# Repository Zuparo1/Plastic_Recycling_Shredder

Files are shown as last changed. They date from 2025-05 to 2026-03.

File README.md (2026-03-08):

# 🌍 Open-Source Plastic Shredder for 3D Printing Waste

**A modular, self-fabricated shredder designed for labs, makerspaces, and classrooms around the world. Built with affordable materials and hobby-grade tools, this project supports circularity, sustainability, and accessible engineering.**

Animations: 
https://drive.google.com/drive/folders/1GTDH_LksxOAHPd8L4uIryJ2b2BNffAHZ?usp=sharing
---

##  About the Project

As 3D printing becomes more widespread, so does its waste—failed prints, supports, and excess prototypes. This open-source shredder enables small-scale recycling of that plastic into material suitable for extrusion into new filament.

Our design prioritizes:
-  **Making** – We emphasize fabrication, not just CAD.
-  **Accessibility** – Built from globally available tools and materials.
-  **Sustainability** – Aligned with UN SDG 12 for circular production.

All files, documentation, and build guides are included to help you fabricate and adapt the shredder in your own lab or makerspace.

---

##  What's Included

-  [Build Manual](Manual.pdf): Step-by-step instructions with safety tips and fabrication guidelines
-  [STEP](/STEP) files for the Shredder, gearbox, and housing
-  [Fusion 360](Fusion%20Models) files
-  [Arduino code](ArduinoCode/ArduinoDigiFabFinal/ArduinoDigiFabFinal.ino)
-  [Bill of materials](/Bill%20of%20Materials) with sourcing notes

---

##  What You'll Need

**Tools:**
- Laser cutter
- FDM 3D printer (e.g., Prusa, Creality)
- CNC router (optional for motor mount)
- Basic hand tools and soldering equipment

**Materials:**
- MDF wood (6mm / 16mm)
- PLA, ABS, or PC+ filament
- Bearings (608ZZ, 6002 2RS, etc.)
- Bolts and nuts (M3–M6)
- Gear motor (~\$40, or cheaper alternatives)

Full details in the [manual](Manual.pdf).

---

##  How It Works

1. Print your model
2. Shred failed or excess prints into pellets
3. Extrude into new filament
4. Repeat 

---

##  License

This project is released under the **CERN-OHL-W v2** license, allowing you to use, modify, and distribute it freely, with the condition that improvements are shared under the same license.

---

##  Contributions Welcome

Feel free to fork, remix, or submit pull requests for improvements! We welcome:
- Translations
- Alternative gear/motor configurations
- Safety features or electronics add-ons
- Field testing results

---

## 📫 Contact

Made by  
- Torstein Mo Kirkeluten – `torstemk@hiof.no`  
- Jacob Holth – `jacobh@hiof.no` /  `Zuparo1@hotmail.com`
- Moritz P. Nedland Halkjelsvik – `mphalkje@hiof.no`

Faculty of Computer Science, Engineering and Economics  
Østfold University College, Norway

---

*Help us make sustainable 3D printing a global reality.*

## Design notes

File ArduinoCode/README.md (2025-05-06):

This fodler contains the code for the Arduino Control Box

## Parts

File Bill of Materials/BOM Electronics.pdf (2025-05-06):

# BOM Electronics

This document outlines essential components required for building the shredder.

## Components

The following table lists the components necessary for assembling the electronics. Optional components are marked with *

ID | Item | Material | Quantity | Link
1 | Arduino Uno | | 1 | https://store.arduino.cc/products/ard uino-uno-rev3?srsltid=AfmBOoryz0 R57xpHzzZM81fNsVgdM2d6e5Gq1 D9oCW6n_iAZb1saQQDX (https://store.arduino.cc/products/arduino-uno-rev3)
2 | 16x2 I2C LCD Display Address: 0x27 | | 1 | https://www.aliexpress.us/item/1005 006085343415.html?src=google&pd p_npi=4%40dis%21EUR%211.21% 211.21%21%21%21%21%21%40% 2112000035661666782%21ppc%2 1%21%21&src=google&albch=shop ping&acnt=298-731-3000&isdl=y&sl nk=&plac=&mtctp=&albbt=Google_ 7_shopping&aff_platform=google&a ff_short_key=UneMJZVf&gclsrc=aw. ds&albagn=888888&ds_e_adid=&d s_e_matchtype=&ds_e_device=c&d s_e_network=x&ds_e_product_grou p_id=&ds_e_product_id=en100500 6085343415&ds_e_product_merch ant_id=5089408953&ds_e_product _country=NO&ds_e_product_langu age=en&ds_e_product_channel=onl ine&ds_e_product_store_id=&ds_ur l_v=2&albcp=21627925185&albag= &isSmbAutoCall=false&needSmbH ouyi=false&gad_source=1&gad_ca mpaignid=21634522559&gbraid=0A AAAAqc5ie1OKkm5g4Uzg7gkq1CR bybP_&gclid=Cj0KCQjw5ubABhDIA RIsAHMighZQxXRg8FOkbWryVEXl rHnaxIR6BKWgDFGf5LjG0Isgq0eE oFPellsaAloSEALw_wcB&gateway Adapt=glo2usa (https://www.aliexpress.us/item/1005006085343415.html?src=google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)
3 | Momentary Push Button | | 1 | https://www.aliexpress.us/item/3256 (https://www.aliexpress.us/item/3256805662396061.html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)

## Components

The following table lists the components necessary for assembling the electronics. Optional components are marked with *

ID | Item | Material | Quantity | Link
| | | | 805662396061.html?spm=a2g0o.pr oductlist.main.21.6cbf1f18OKJsNd& algo_pvid=3d2ef3f2-b68c-44ce-b9fd -54fd0e0a57cc&algo_exp_id=3d2ef 3f2-b68c-44ce-b9fd-54fd0e0a57cc- 10&pdp_ext_f=%7B%22order%22% 3A%2275%22%2C%22eval%22%3 A%221%22%7D&pdp_npi=4%40dis %21USD%211.76%211.56%21%21 %211.76%211.56%21%402103956 a17465421417618754e26d2%2112 000034565686333%21sea%21US %210%21ABX&curPageLogUid=7P etJtaaquGC&utparam-url=scene%3 Asearch%7Cquery_from%3A (https://www.aliexpress.us/item/3256805662396061.html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)
4 | WS2812B LED Strip 4 LEDs | | 1 | https://www.fibel.no/product/ws2812 b-neopixel-pixel-led-strip/?srsltid=Af mBOopAH0Vv36monS-HPZx3gQyJ 3OkJDmQXrJ0zuG5A_po6k7F0Jrh T (https://www.fibel.no/product/ws2812b-neopixel-pixel-led-strip/)
5 | Piezo Buzzer - PKM22EPPH4002-B0 | | 1 | https://www.digikey.no/no/products/ detail/murata-electronics/PKM22EP PH4002-B0/2595277?gad_source= 1&gad_campaignid=20277145871& gbraid=0AAAAADrbLlj-o2vP-Egd_Zi Wn0xH5Ob-G&gclid=Cj0KCQjw5ub ABhDIARIsAHMighaVh73Tvg7JnuA 5kcsUhn0y8bUVbFrtSQIoYFb33IgO N_E96ZZn-_UaAvWFEALw_wcB&g clsrc=aw.ds (https://www.digikey.no/no/products/detail/murata-electronics/PKM22EPPH4002-B0/2595277?gad_source=1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)
6 | 220Ω resistor | | 1
7 | Breadboard | | 1
8 | Jumper wires | | 17
9 | Housing | PLA | 1
10 | Housing Lid | PLA | 1

## Components

The following table lists the components necessary for assembling the electronics. Optional components are marked with *

ID | Item | Material | Quantity | Link
11 | Mounting Plate | PLA | 1
12 | M3 Screw 16 | Steel | 11
13 | M3 Bolt | Steel | 22
14 | USB A to USB B cable 1.5m | | 1
15 | 5V USB A Power adapter | | 1

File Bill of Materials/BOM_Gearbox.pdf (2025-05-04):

# BOM Gearbox

The gearbox features a modular design composed of various interchangeable parts. This document outlines essential components required for building a single gearbox module, as well as additional components for constructing expansion modules.

## Essential internal components

The following table lists the critical internal components necessary for assembling a single gearbox module.

ID | Item | Material | Quantity | Link
1 | Input Gear | PC+ | 1
2 | Planet Gear | PLA | 4
3 | 608 - ZZ Ball Bearing | Steel | 4 | 608 - ZZ Deep Groove Ball Bearing (https://www.amazon.com/SACKORANGE-100-608-ZZ-Ball-Bearing/dp/B07JB2Y4H3?cv_ct_cx=8mm+id+bearing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)
4 | OutputHub | PLA | 1
5 | 6002-2RS Ball Bearing | Steel | 1 | 6002-2RS Deep Groove Ball Bearing (https://www.amazon.com/dp/B0D8GQGH4Y?s=industrial&sp_csd=d2lkZ2V0TmFtZT1zcF9kZXRhaWwy)
6 | 685-2RS Ball Bearing | Steel | 1 | 685-2RS Deep Groove Ball Bearing (https://www.amazon.com/HARFINGTON-6810-2RS-Bearings-Bearing-Conveyors/dp/B0CGXDDZ8F)
7 | Ring Gear | PLA | 1
8 | Housing (See options) | PLA | 1
9 | Faceplate | PLA | 1
10 | M3 Screw (20-30mm) | Steel | 5
11 | M3 HexNut | Steel | 5
12 | M8 Screw (20-25mm) | Steel | 4
13 | M8 HexNut | Steel | 4

## Expansion components

The components listed below are necessary for building additional modules to expand the gearbox, allowing for greater gear ratios and torque based on specific project requirements.

ID | Item | Material | Quantity | Link
14 | Sun Gear Carrier | PLA | 1
5 | 6002-2RS Ball Bearing | Steel | 1 | 6002-2RS Deep Groove Ball Bearing (https://www.amazon.com/dp/B0D8GQGH4Y?s=industrial&sp_csd=d2lkZ2V0TmFtZT1zcF9kZXRhaWwy)
2 | Planet Gear | PLA | 4
3 | 608 - ZZ Ball Bearing | Steel | 4 | 608 - ZZ Deep Groove Ball Bearing (https://www.amazon.com/SACKORANGE-100-608-ZZ-Ball-Bearing/dp/B07JB2Y4H3?cv_ct_cx=8mm+id+bearing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)
7 | Ring Gear | PLA | 1
8 | Housing (See options) | PLA | 1
10 | M3 Screw (20-30mm) | Steel | 5
11 | M3 HexNut | Steel | 5
12 | M8 Screw (20-25mm) | Steel | 4
13 | M8 HexNut | Steel | 4

## Housing Options

Below are listed various housing designs available for the gearbox. All housings are 3D printed in PLA but feature different configurations based on mounting preferences, intended use (single or double gearbox configurations), and specific project needs.

Item

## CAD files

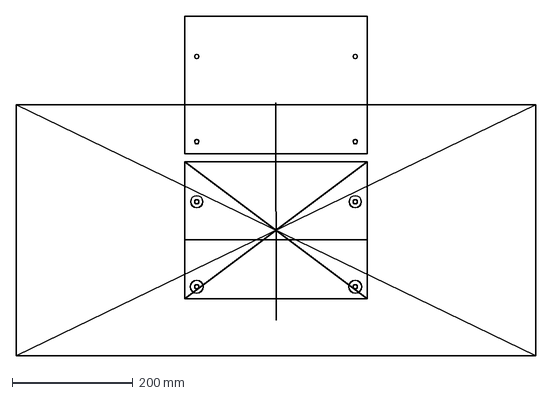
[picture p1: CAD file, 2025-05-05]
Fusion Models/Mountingplate_Cnc.dxf
859.0 x 561.0 mm

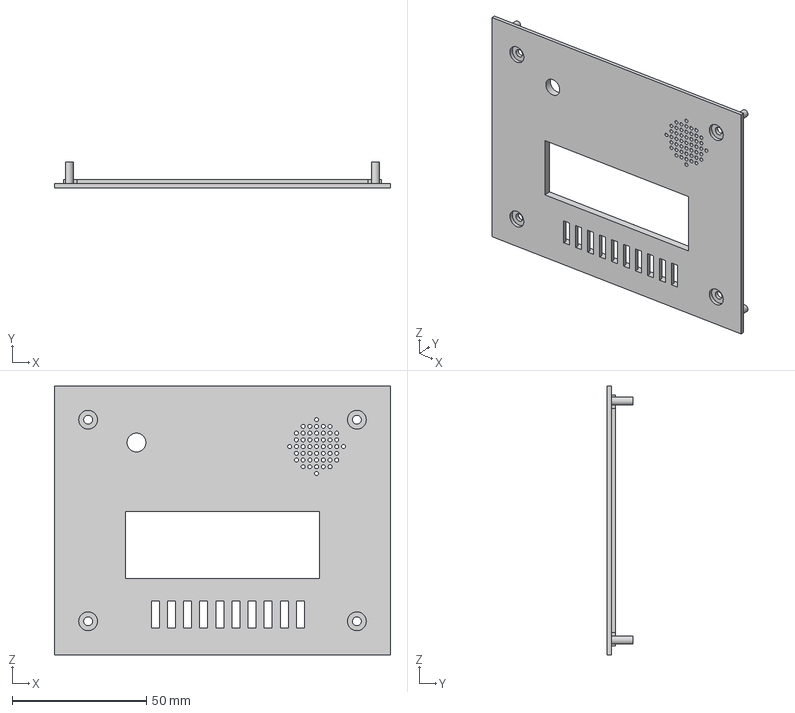
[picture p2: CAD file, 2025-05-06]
STEP/ArduinoControlBox/Arduino_HousingLid _v3.step
125.0 x 9.50 x 100.0 mm

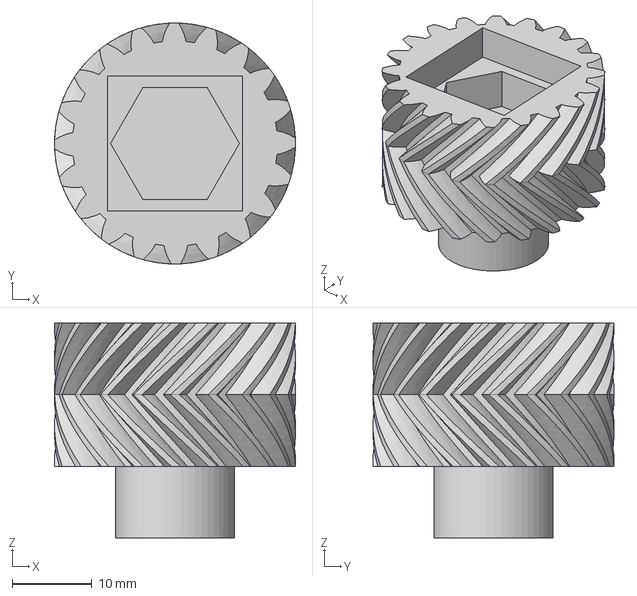
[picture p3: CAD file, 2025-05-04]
STEP/Gearbox/SunGear.step
30.3 x 30.3 x 27.0 mm

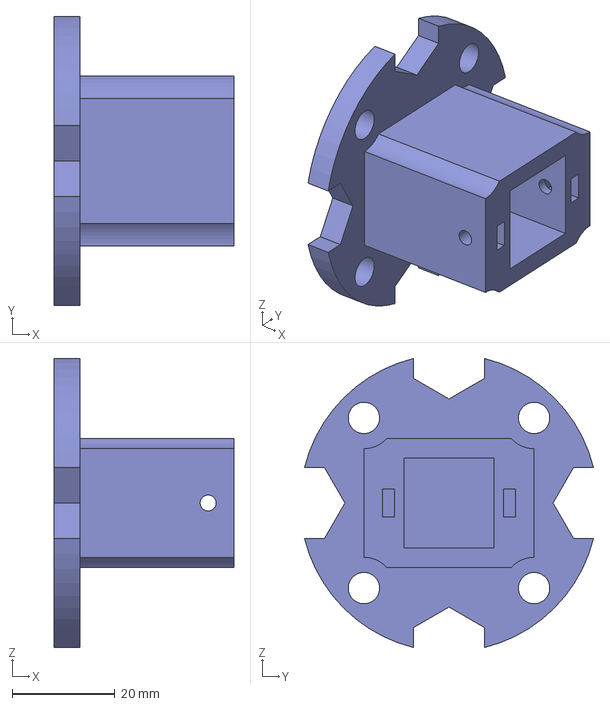
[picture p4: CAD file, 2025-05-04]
STEP/Shredder/GearBox_Axle_Conector.step
35.0 x 56.3 x 56.3 mm

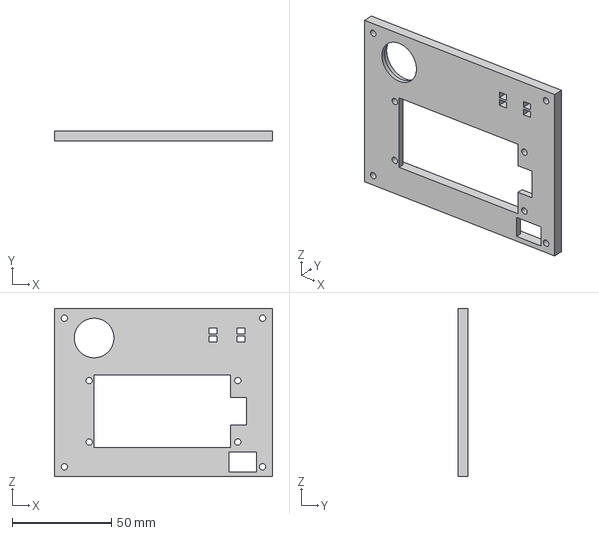
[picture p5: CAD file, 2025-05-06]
STEP/ArduinoControlBox/Arduino_MountingPlate_v4.step
110.0 x 5.00 x 85.0 mm

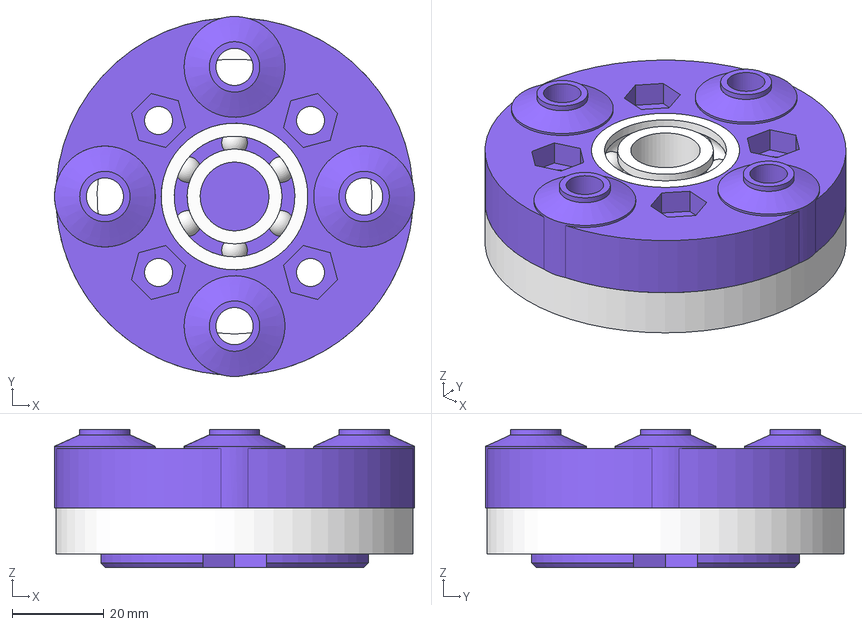
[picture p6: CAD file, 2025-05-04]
STEP/Gearbox/OutputHub.step
78.6 x 78.6 x 30.2 mm
OuterRing
InnerRing
Ball x 6
OuterRing_1
InnerRing_1
Ball_1 x 19

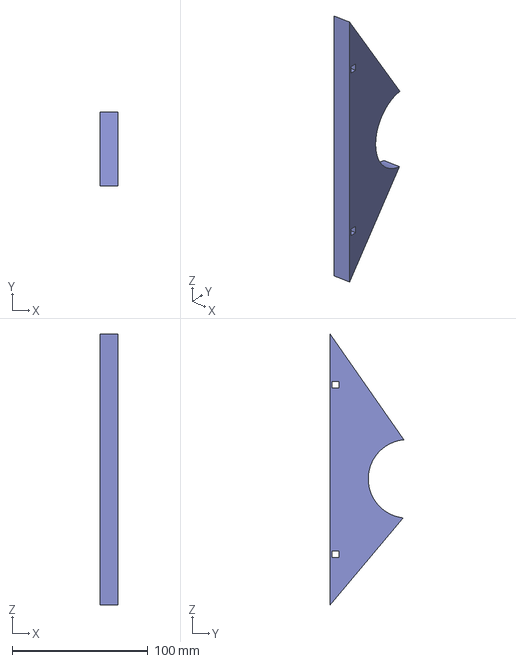
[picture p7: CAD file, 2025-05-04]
STEP/Shredder/wall_spacer.step
13.2 x 54.4 x 200.0 mm

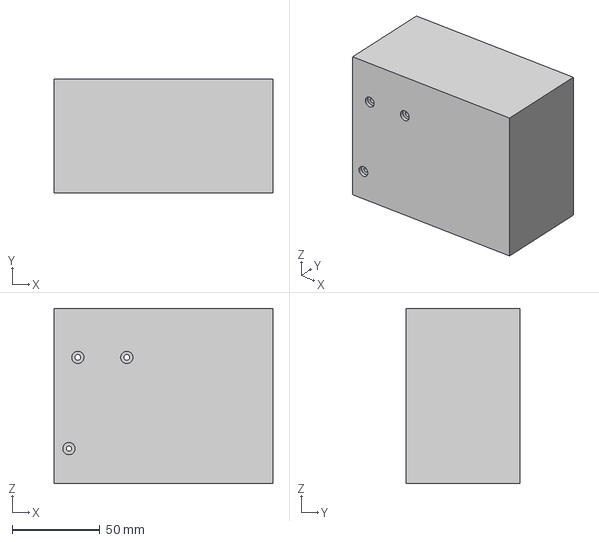
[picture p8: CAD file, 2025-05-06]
STEP/ArduinoControlBox/Arduino_Housing_v7.step
125.0 x 65.0 x 100.0 mm

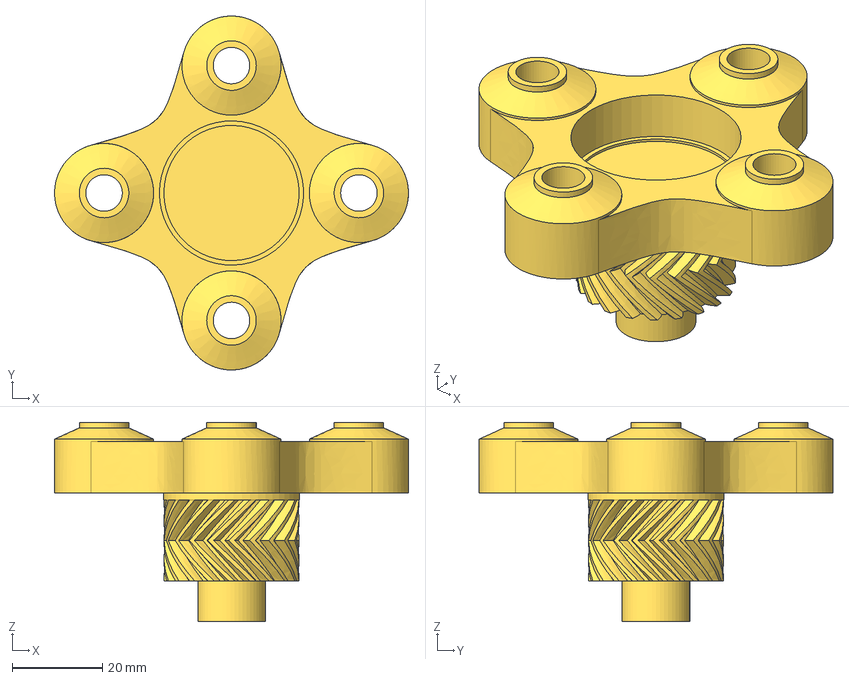
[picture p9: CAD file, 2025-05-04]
STEP/Gearbox/SunGearCarrier.step
78.6 x 78.6 x 44.2 mm

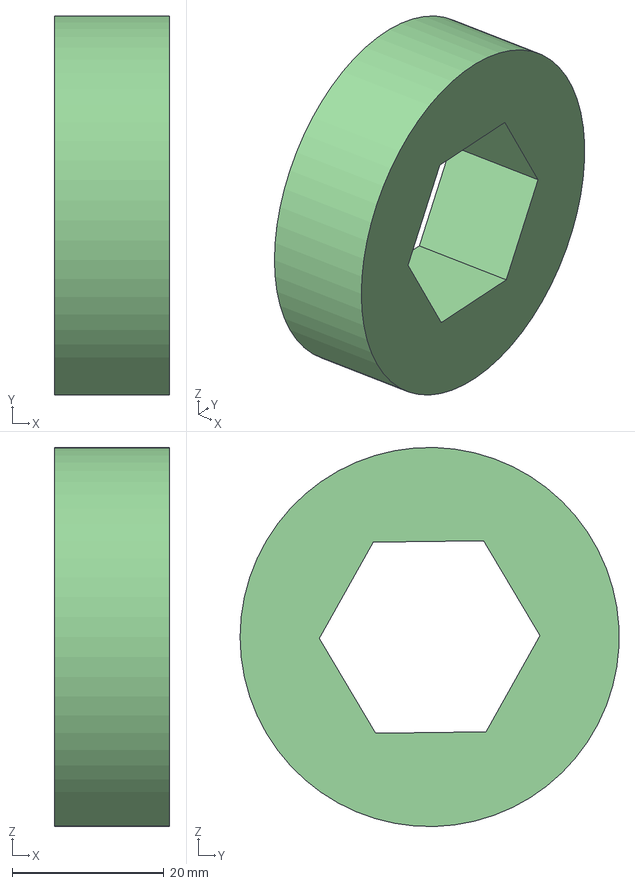
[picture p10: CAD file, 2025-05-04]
STEP/Shredder/Axle_spacer.step
15.2 x 50.0 x 50.0 mm

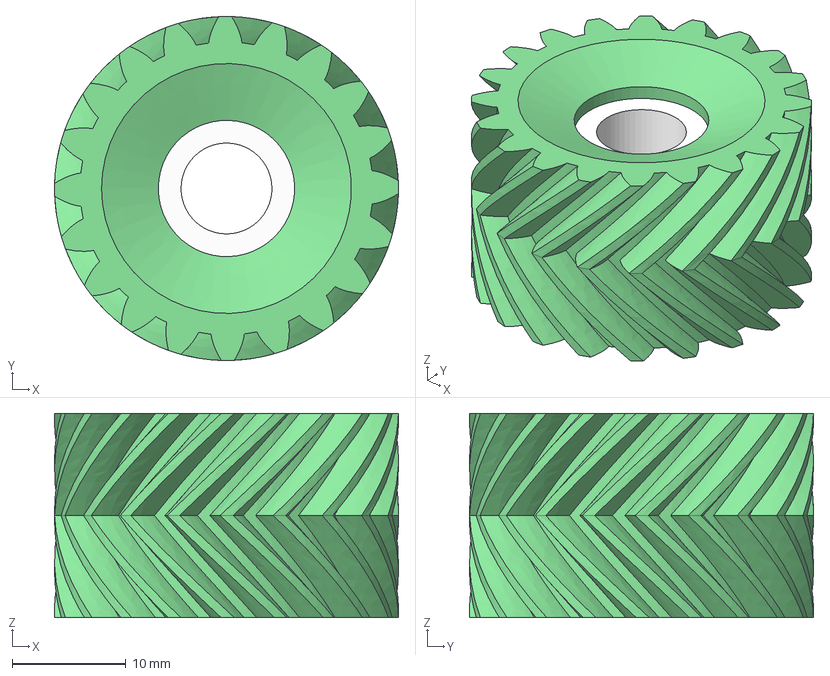
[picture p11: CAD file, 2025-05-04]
STEP/Gearbox/PlanetGear v5.step
30.3 x 30.3 x 18.0 mm
PlanetGear_1
OuterRing
InnerRing
Ball x 4

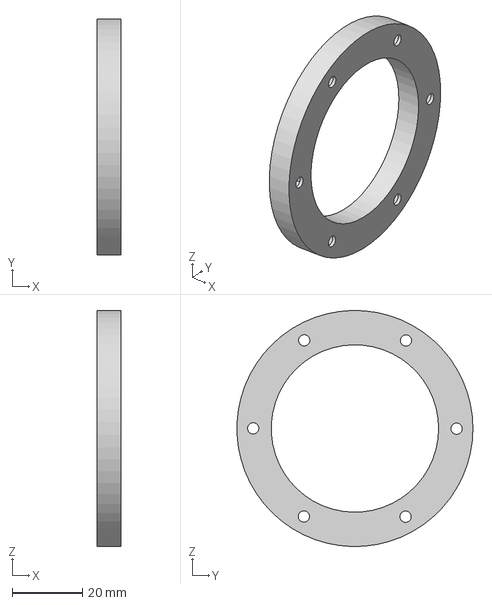
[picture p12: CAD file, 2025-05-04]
STEP/Shredder/Bearing_connector_back.step
6.80 x 67.0 x 67.0 mm

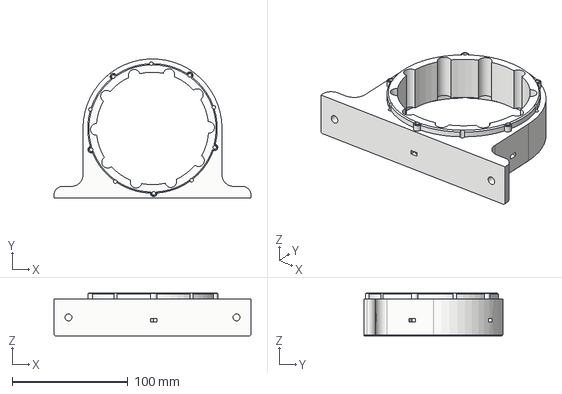
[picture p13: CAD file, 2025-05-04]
STEP/Gearbox/RingGearHolderMount.step
170.0 x 119.9 x 37.0 mm

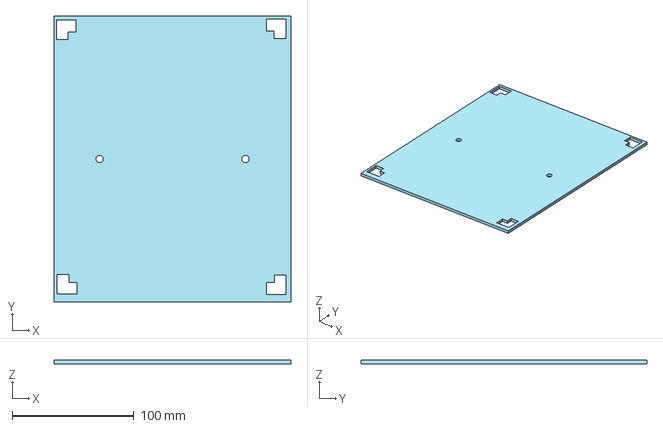
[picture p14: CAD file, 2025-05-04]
STEP/Shredder/roof.step
195.0 x 235.0 x 3.00 mm

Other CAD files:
STEP/Gearbox/RingGearHolderMountDouble v3.step
STEP/Shredder/Wall_spacer_mount.step
STEP/Gearbox/RingGearHolder.step
STEP/Shredder/wall_conectors.step
Fusion Models/Arduino_Housing_v7.f3d
Fusion Models/Arduino_MountingPlate_v4.f3d
Fusion Models/HousingLid v3.f3d
Fusion Models/Main_Shredder.f3z
STEP/Gearbox/FacePlate v2.step
STEP/Gearbox/MotorMount v2.step
STEP/Gearbox/RingGear.step
STEP/Shredder/Axle.step
STEP/Shredder/Bearing_connector_front.step
STEP/Shredder/FrontBack_wall.step
STEP/Shredder/Shredder_Blade.step
STEP/Shredder/roof_handle.step
STEP/Shredder/side_wall.step

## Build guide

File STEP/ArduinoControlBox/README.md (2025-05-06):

STEP Files for the housing unit, used for the Arduino Control Box.

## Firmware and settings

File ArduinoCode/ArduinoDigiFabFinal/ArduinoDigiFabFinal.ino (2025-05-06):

#include <Wire.h>
#include <LiquidCrystal_I2C.h>
#include <Adafruit_NeoPixel.h>

const int buttonPin = 2;
const int buzzerPin = 4;
const int ledPin = 6;

const int numLEDs = 4;
Adafruit_NeoPixel strip(numLEDs, ledPin, NEO_GRB + NEO_KHZ800);
LiquidCrystal_I2C lcd(0x27, 16, 2);


enum ScreenState { STARTUP, IDLE, START_RUNTIME, SHREDDING, DONE };
ScreenState currentScreen = STARTUP;


unsigned long shredStartTime = 0;
unsigned long lastTimerUpdate = 0;
float finalShredTime = 0.0;


bool buttonLock = false;
unsigned long lastButtonTime = 0;
const unsigned long debounceDelay = 300;

void setup() {
  pinMode(buttonPin, INPUT_PULLUP);  
  pinMode(buzzerPin, OUTPUT);

  lcd.init();
  lcd.backlight();
  strip.begin();
  strip.show();

  showStartup(); 
  setLEDColor(0, 255, 0);
}

void loop() {
  unsigned long now = millis();
  int buttonState = digitalRead(buttonPin);

  
  if (buttonState == HIGH && !buttonLock && now - lastButtonTime > debounceDelay) {
    lastButtonTime = now;
    buttonLock = true;
    nextScreen(); 
  }

  if (buttonState == HIGH) {
    buttonLock = false;
  }


  if (currentScreen == SHREDDING) {
  unsigned long now = millis();

  if (now - lastTimerUpdate >= 500) {
    lastTimerUpdate = now;
    float elapsed = (now - shredStartTime) / 1000.0;
    lcd.setCursor(6, 1);
    lcd.print("          ");
    lcd.setCursor(6, 1);
    lcd.print(elapsed, 1);
    lcd.print("s");
  }


  static unsigned long lastFlashTime = 0;
  static bool isYellowOn = false;

  if (now - lastFlashTime >= 500) {
    lastFlashTime = now;
    isYellowOn = !isYellowOn;

    if (isYellowOn) {
      setLEDColor(255, 255, 0);  
    } else {
      setLEDColor(0, 0, 0);      
    }
  }
}
}


void nextScreen() {
  currentScreen = static_cast<ScreenState>((currentScreen + 1) % 5);

  switch (currentScreen) {
    case STARTUP:
      showStartup();
      setLEDColor(0, 255, 0); 
      break;
    case IDLE:
      showIdle();
      setLEDColor(0, 255, 0); 
      break;
    case START_RUNTIME:
      showStartRuntime();
      setLEDColor(0, 255, 0); 
     break;
    case SHREDDING:
      showShredding();
      tone(buzzerPin, 500, 300); 
      setLEDColor(255, 255, 0); 
      break;
    case DONE:
      finalShredTime = (millis() - shredStartTime) / 1000.0;
      showDone();
      tone(buzzerPin, 700, 300);
      delay(500);
      tone(buzzerPin, 700, 300);
      setLEDColor(0, 0, 255);
      break;
  }
}

void showStartup() {
  lcd.clear();
  lcd.setCursor(0, 0);
  lcd.print("Shredder ready");
  lcd.setCursor(0, 1);
  lcd.print("Insert material");
}

void showIdle() {
  lcd.clear();
  lcd.setCursor(0, 0);
  lcd.print("Secure lid");
  lcd.setCursor(0, 1);
  lcd.print("Next page...");
}

void showStartRuntime() {
  lcd.clear();
  lcd.setCursor(0, 0);
  lcd.print("For runtime:");
  lcd.setCursor(0, 1);
  lcd.print("Press when start");
}

void showShredding() {
  lcd.clear();
  lcd.setCursor(0, 0);
  lcd.print("Shredding...");
  lcd.setCursor(0, 1);
  lcd.print("Time: 0.0s");

  shredStartTime = millis();
  lastTimerUpdate = millis();
}

void showDone() {
  lcd.clear();
  lcd.setCursor(0, 0);
  lcd.print("Shredding Done");
  lcd.setCursor(0, 1);
  lcd.print("Time: ");
  lcd.print(finalShredTime, 1);
  lcd.print("s");
}

void setLEDColor(int r, int g, int b) {
  for (int i = 0; i < numLEDs; i++) {
    strip.setPixelColor(i, strip.Color(r, g, b));
  }
  strip.show();
}

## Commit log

2025-05-06 Add files via upload
    HousingLid
    [HousingLid v3.f3d]
2025-05-06 Add files via upload
    Arduino_MountingPlate_v4 and Arduino_Housing_v7 upload
    [Arduino_Housing_v7.f3d, Arduino_MountingPlate_v4.f3d]
2025-05-06 Add files via upload
    All three current files for the Arduino Control Box housing.
    [Arduino_HousingLid _v3.step, Arduino_Housing_v7.step, Arduino_MountingPlate_v4.step]
